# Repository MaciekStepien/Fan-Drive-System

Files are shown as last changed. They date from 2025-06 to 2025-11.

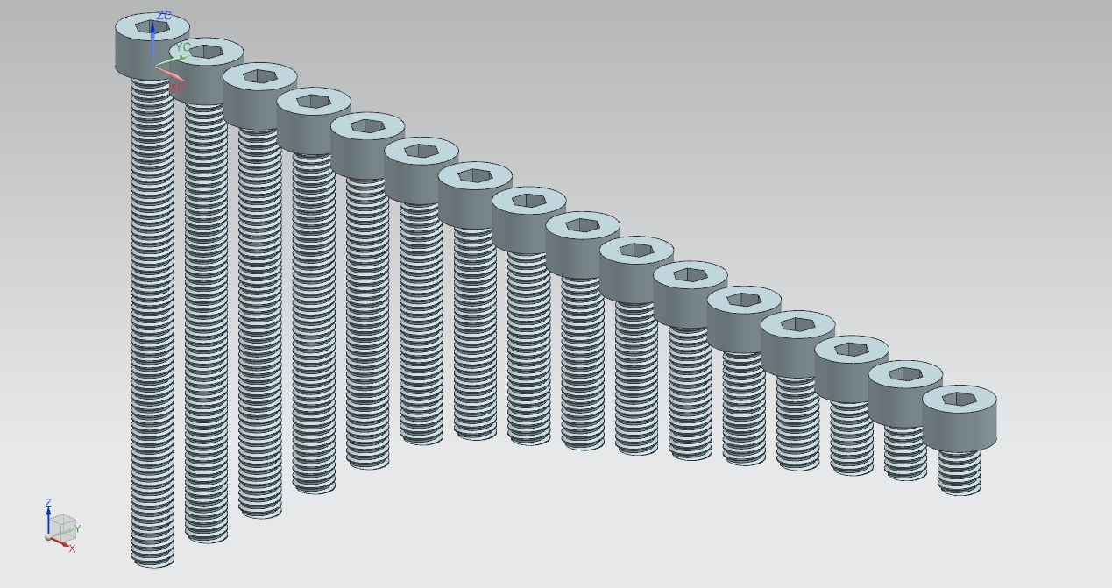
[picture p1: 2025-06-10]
Model/M4 Allen screws/Renderings/M4.jpg

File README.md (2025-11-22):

## About

This repository includes the complete design of a Fan Drive System, developed using Siemens NX CAD software. The project showcases:

- A parametric 3D model of the Fan Drive System enabling flexible design adjustments.
- A technical report providing detailed engineering calculations that support design decisions.
- Precise technical drawings extracted from the CAD model for manufacturing and review.

This work demonstrates practical expertise in computer-aided design, mechanical engineering analysis, and power transmission system design relevant to rotating machinery.

---

## Repository Structure

- `Model/` — Siemens NX model files containing all parametric design data
- `Drawings/` — Technical drawings in PDF format
- `Report_EN.pdf` — Engineering report in PDF format with calculations in English
- `Rerport_PL.pdf` — Engineering report in PDF format with calculations in Polish
- `README.md` — This project overview document

---

## How to Use

- Open the 3D model files in Siemens NX or compatible CAD software to explore, modify, or simulate the Fan Drive System.
- Refer to the engineering report for comprehensive details about design parameters, calculation methodologies, and technical specifications.
- Use the included technical drawings for manufacturing or detailed review purposes.
  
> **Note:** The report was originally written in Polish. The English version has been auto-translated using DeepL for convenience.  
> As a result, the translation may contain inaccuracies. Please refer to the original Polish version for the most reliable information.

---

## Highlights

- Parameter-driven CAD model for easy customization.
- In-depth mechanical analysis to ensure design reliability and performance.
- Detailed drawings suitable for prototyping or production.

---

## Contact

For any questions, feedback, or collaboration inquiries, please get in touch with Maciej Stępień.

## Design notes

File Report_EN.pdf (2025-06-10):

## Faculty of Power and Aeronautical Engineering Institute of Aeronautical Technology and Applied Mechanics Department of Fundamentals of Construction

## Fundamentals of Mechanical Engineering VI

# Fan Drive Transmission System

Performed by: Maciej Stępień | Verified by: Marcin Obszański

Subscribe to DeepL Pro to translate larger documents. Visit www.DeepL.com/pro (https://www.deepl.com/pro?cta=edit-document&pdf=1) for more information.

## Table of Contents

1 | Introduction | 4
1.1 | Outline drawing | 4
1.2 | Design assumptions | 5
1.2.1 | Gabarites | 6
1.3 | Materials used in the device | 7
1.4 | Safety factor | 7
2 | Motor selection | 7
3 | Belt transmission | 8
4 | Shaft loads | 9
4.1 | Shaft diameter arrangement | 9
4.2 | Shaft statics | 10
4.3 | Distribution of effort components | 11
5 | Determination of shaft diameters | 13
5.1 | Ad hoc strength | 13
5.2 | Static stiffness of the shaft | 13
5.3 | Critical rotation of the shaft | 14
5.4 | Fatigue strength analysis of the shaft | 14
6 | Bearing selection | 16
7 | Inlets | 17
8 | Frame statics | 17
9 | Description of the belt tensioning system | 19
10 Sources | 19

## 1 Introduction

The purpose of this work is to design a transmission system for a fan, driven by an electric motor, from which torque is transferred to the shaft by means of a belt transmission, equipped with a belt tensioning system. All components of the device are mounted on a welded frame. The shaft is bearing between the fan and the passive pulley.
1.1 Drawing illustrative

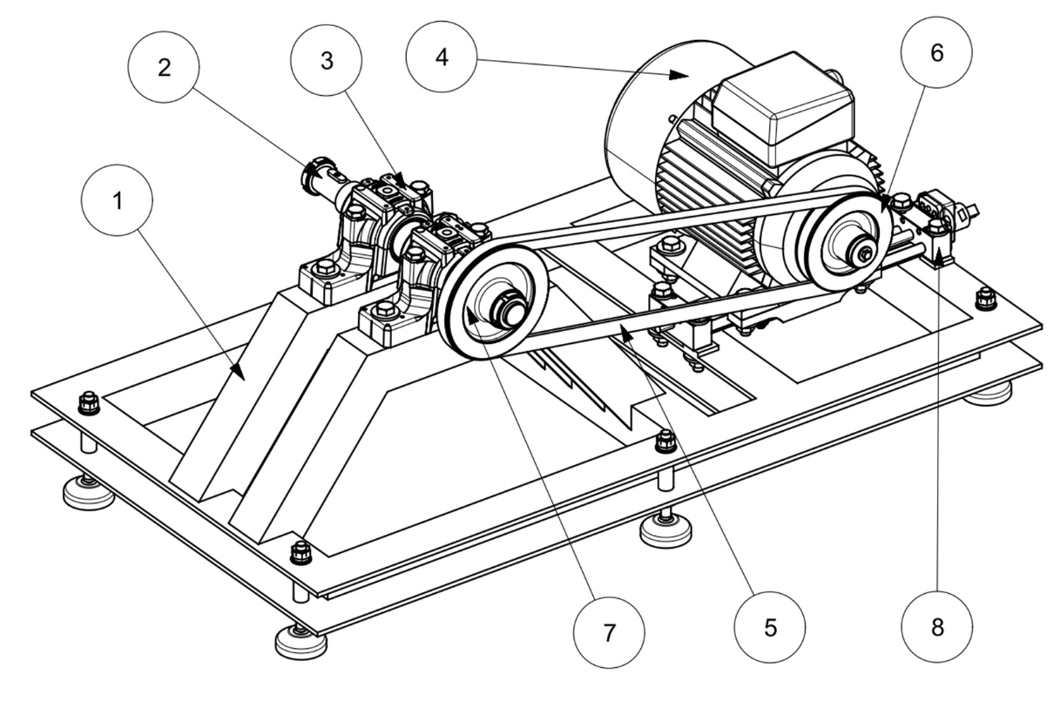
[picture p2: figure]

Main components:

### 1. Frame 2. Drive shaft 3. Bearing housing with bearing 4. Electric motor 5. V-belt 6. Small pulley 7. Large pulley 8. Linear table

1.2 Assumptions design

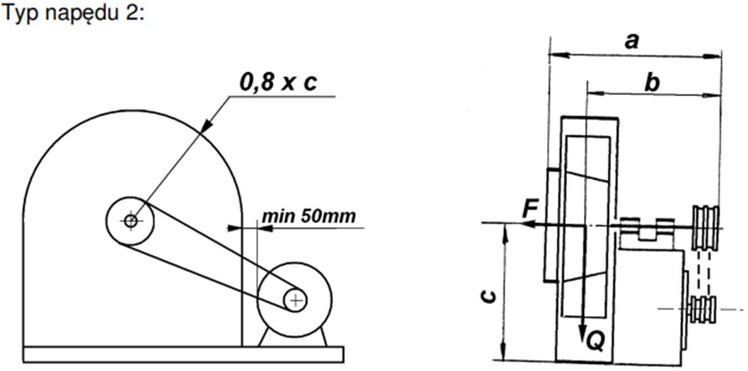
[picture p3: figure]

- two shaft supports are located between the pulley and the rotor

### - power P= 1.2kW

- rotational speed n= 1200 rpm
- axial force F= 310N
- rotor weight Q= 126N
- hourly life L10h= 130000h
- width of the device along the shaft axis a= 505mm
- distance from the center of gravity of the rotor to the opposite end of the shaft b=440mm (later changed to b= 383)
- height of the shaft axis from the ground c= 320mm
- spacing between motor and rotor housing - min 50mm

1.2.1 Gabaryty

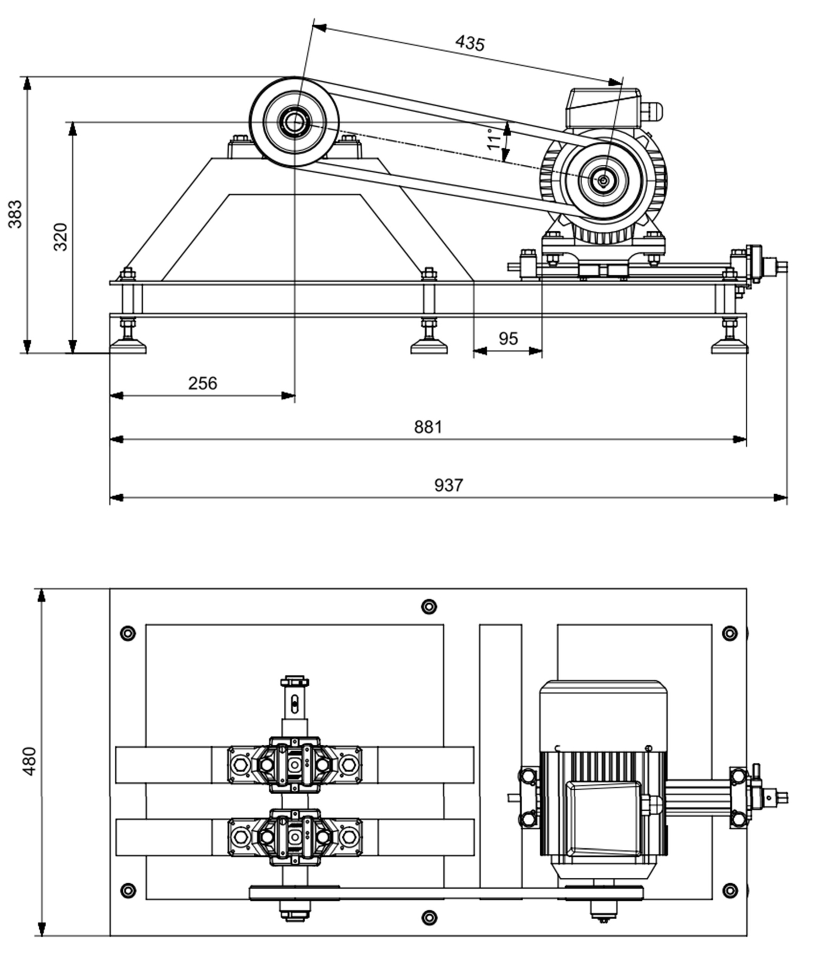
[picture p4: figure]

1.3 Materials used in device
- shaft, disc protection disc on motor shaft: C35 (Re= 270MPa, Rm= 520MPa, Zsj= 244MPa, Zgj= 364MPa, Zso= 150MPa, Zgo= 250MPa)
- Frame, engine mounting table: S235JR (Re= 235MPa, Rm= 410MPa)
- pulleys: St3SX (Rm= 360MPa)
- keys: C45 (Re= 360MPa, Rm= 610MPa, Zsj= 340MPa, Zgj= 480MPa, Zso= 170MPa, Zgo= 280MPa)
- Bushings for pulley, rotor: AISI 303 (Re= 190MPa, Rm= 500MPa)
- shims under the guide: SBR rubber

The selection of materials was based on an analysis of similar components available on the market. All other parts are standardized and made by third-party manufacturers.

1.4 Factor safety
The designed device is to operate most of the day, under moderate loads. The adopted safety factor is x=4.

## 2 Selection of

motor | Pwy
| 5upn

1,2 kW
=
0,945

= 1,269 kW

Assuming 5upn= 5p.belt ∙ 5bearings= 0.95∙ 0.995 = 0.94525 [1]. SH 90 L-4 motor

with parameters was selected:
- Rated powerPse= 1.5 kW
- Speed n= 1410 rpm

The motor meets the design requirements by a margin. In addition, reduce the speed and power of the motor.

## 3 Transmission belt transmission

The designation and selection of belt transmission components were made based on [2]. A SPA V-belt was decided upon. Calculations were made on pulley diametersdp= 100 andDp= 118 (normalized values, selected on the basis of [2]).

The value of the actual ratio of such a gearbox is:
Dp

## irz=

d

118
= = 1.18
100

While the necessary gear ratio, resulting from the characteristics of the selected engine and from the project's assumptions, is:

The ratio error is:
irz−i
i

i= 1.175

- 100%= 0.425%

According to [1], this is an acceptable error.

Then calculated / selected (based on [2]):

- WheelbaseA0:

AdoptedA1= 0.435 m

- Lane lengthLp:

A0min= 0.7∙ (D(p)+d(p)) = 0.1526 A0ma=2∙ (D(p)+d(p)) = 0.436

2
(D(p)−dp)
Lp_calculated= 2 ∙A + 1.57∙ (D(p)+d(p) ) + | = 1,212 m
4A
The normalized lane lengthLp= 1,207m , according to [2], was assumed.
- Exact wheelbase :A

Where:

A≈p+√p²−q= 0.432m

p= 0.25L(p)− 0.393(D(p)+dp) = 0,216

2
q= 0.125(D(p)−dp) = 3.83∙ 10
- Operating conditions factor:kt = 1.2, assuming an operating time of more than 16 hours per day for light drive
- Banding factor:kφ= 0.99
φ

## cos

2

Dp−dp =
2A

→ φ= 177.68°
- Lane length ratio: kL= 0.88
- Rated power:N1= 2.54 kW

p

-5

dyn

- Required number of transmission belts:
z =

N∙kt = 0,813

N1∙kφ∙kL
Rounding up, a single belt was used in the gearbox.

The forces acting on the belt, were also calculated according to [2]. In the design, the case that is most "dangerous" for the system should be checked. Therefore, it was decided to take into account the dynamic force.

- Dynamic axle load from forces in the passive tendons:
1020∙ (1.02 −kφ) ∙N∙kt
T(b) ≈ | kφ

= 7,536 N
- v

Where the lane movement speed: v= 7.38 m/s

- Dynamic axle load from forces in active tendons: 1020 ∙N ∙ kt
T(c) ≈
- Accidental dynamic force:

kφ

= 251,2 N
- v

Ns ≈√Tc
2+Tb

2+ 2 ∙Tc∙Tb∙ cosφ= 258.73 N

## 4 Loads shaft

4.1 Arrangement of diameters of the shaft

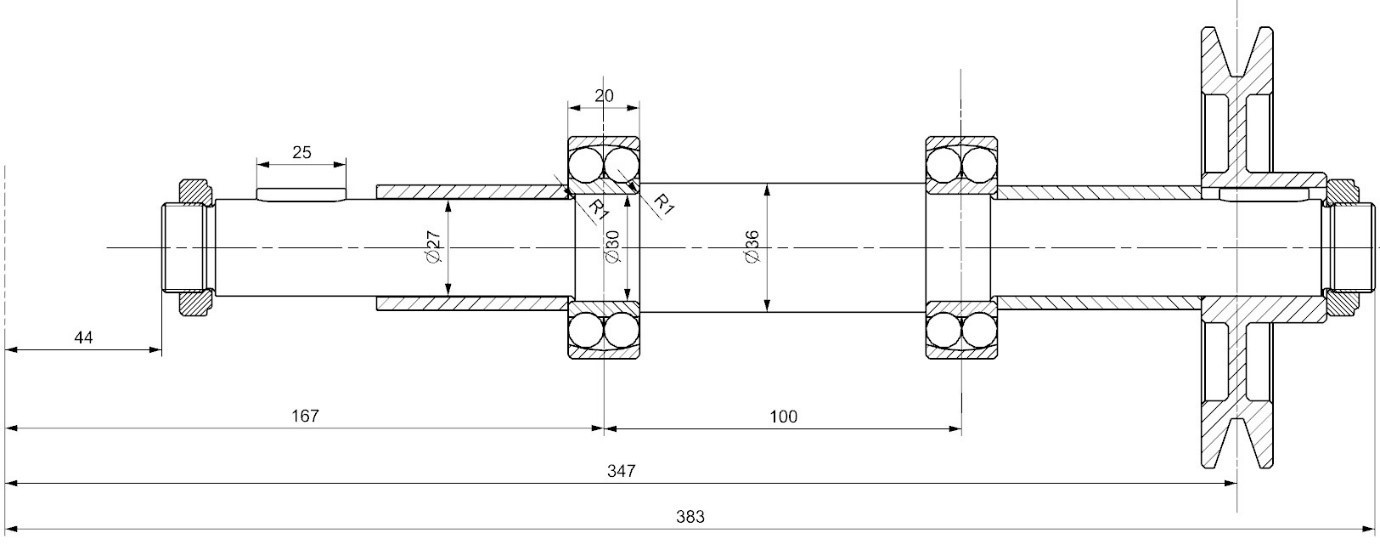
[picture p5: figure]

The above figure shows the arrangement of the various elements on the shaft, the distances between them and the lengths of the various segments of the shaft.

4.2 Statics of the shaft

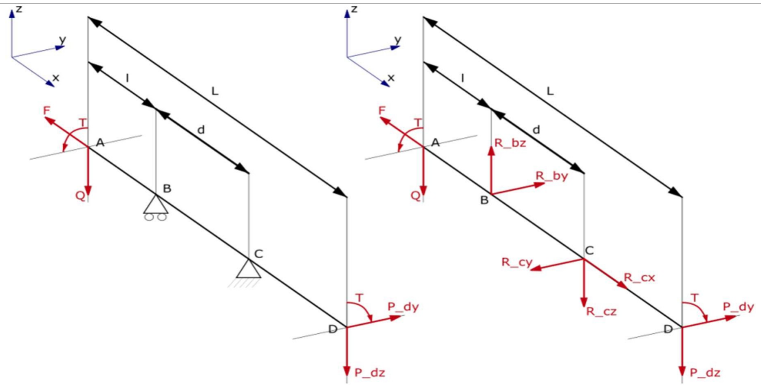
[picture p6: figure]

Data adopted for calculations:

Designation | Value | Unit
L | 0,347 | m
l | 0,167 | m
d | 0,1 | m
F | 310 | N
Q | 126 | N
T | 11,94 | Nm
P_dy | 255,32 | N
P_dz | 41,81 | N

Where the torsional moment from the belt: T=⁽N∙D) (p)

2v
Dynamic force component on y-direction: Pdy=Nsdyn∙ sin α

Dynamic force component on z direction: Pdy =Nsdyn∙ cos α

Where alpha is the angle between the vertical and the dynamic

force from the chord

Freeing the system from ties and calculating the reaction forces in the supports, we get:

Designation | Value | Unit
Rbx | 0 | N
Rby | 204,3 | N
Rbz | 303 | N
Rbw | 365,69 | N
Rcx | 310 | N
Rcy | -459,6 | N
Rcz | 135,2 | N
Rcw | 479 | N

Where
Rbw =√R by

2+R bx

2

Rcw =√R cy

2+R cx

2

The non-sliding base was placed in a more stressed position.

4.3 Distribution of components of effort
All calculations were carried out assuming, the theoretical case in which the shaft starts at the center of gravity of the fan.

## ZX plane

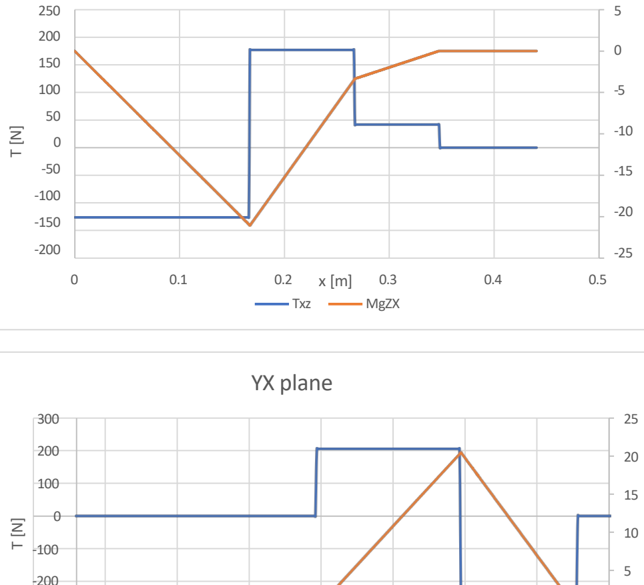
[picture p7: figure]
MgZX; Txz; YX plane
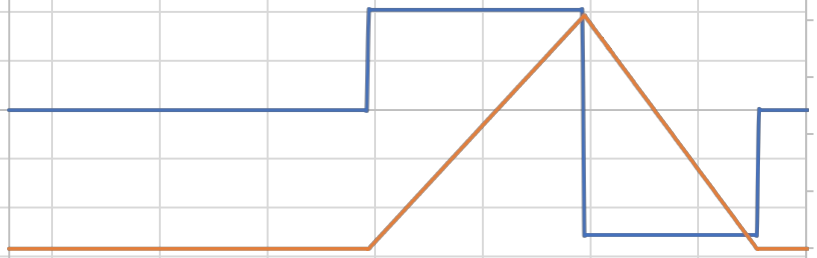
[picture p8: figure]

MgYX

0.17 | 0.22 | 0.27 | 0.32 | 0.37
x [m]
Tyx
0.02 | 0.07 | 0.12
-400 | -5
-0.03
| 0 -300

-200

M [Nm] M [Nm]

After determining the basic load distributions on the shaft, the resultant and equivalent bending moment were calculated:

Mgw =√M yx

2+M zx

2

Mzast=√M(gw) (2)+ (α ∙T )

2

Where α =√

3
4

## Replacement torque 60

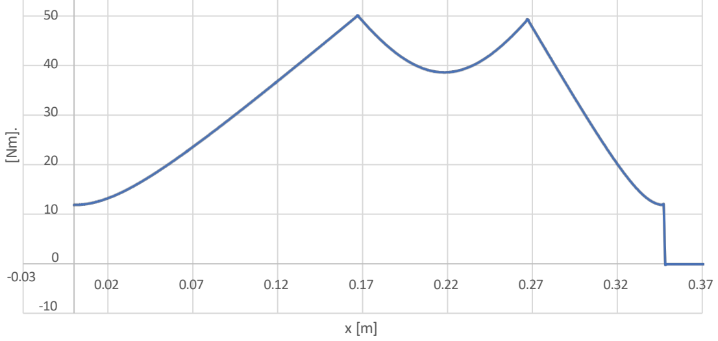
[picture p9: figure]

r>=

## (theor) 0.009

## 5 Determination of shaft diameters

5.1 Strength ad hoc
When determining the theoretical diameter, axial loads were ignored - they have a marginal effect on the obtained results.

Where: x= 4, whileZgo= 250 MPa

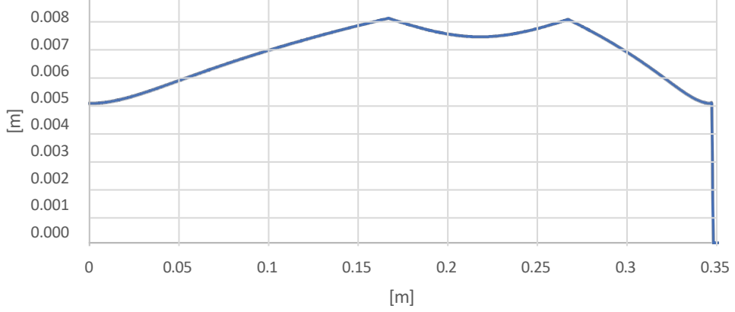
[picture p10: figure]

5.2 Static stiffness of the shaft
A diameter that is the arithmetic average of the two extreme diameters on the shaft was used to calculate the deflection line:
d =

Dmin +D max
2

0.027+ 0.36
=
2

= 0,0315

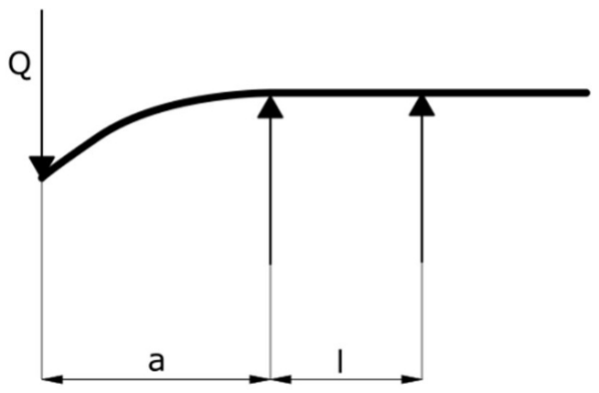
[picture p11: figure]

In addition to this, the load from the gearbox was ignored - only the force is responsible for the deflection . To calculate the deflection line, the formula was used:
Q∙a

2
f = ∙ ( l+ a ) = 3.08∙ 10⁵m 3EJ

Designation | Value | Unit
Q | 126 | N
E | 210 | GPa
J | 4.83∙ 10⁻⁸ | m⁴
l | 0,1 | m
a | 0,167 | m
Where, E is the Young's modulus of C35 steel, and the bending moment of inertia: J= π∙d

4
64
According to [3], the deflection arrow must meet the condition: f= (2÷ 3⁾∙ 10⁴∙l= (2÷ 3⁾∙
10⁵ m

The requirement was not met. After analysis of the critical rotation and consultation with the instructor, the deviation was found to be acceptable.

5.3 Critical rotation of the shaft
The critical speed was obtained from the relationship: :
g | 9,81 | rad

## ωkr=√

f

=√

3.08∙ 10⁵=564 | = 5388 rpm
| | s

The critical speed is more than 4 times the required speed - the shaft meets the requirements.

5.4 Fatigue strength analysis of the shaft
For the fatigue strength analysis of the shaft, 2 cross-sections were selected that may prove to be "weak links". These are the location of the diameter change from the largest diameter to the diameter of the journal on which the bearings are mounted, and the location of the keyhole.

The diagram below shows the moments that were taken into account in the calculations: M [Nm].

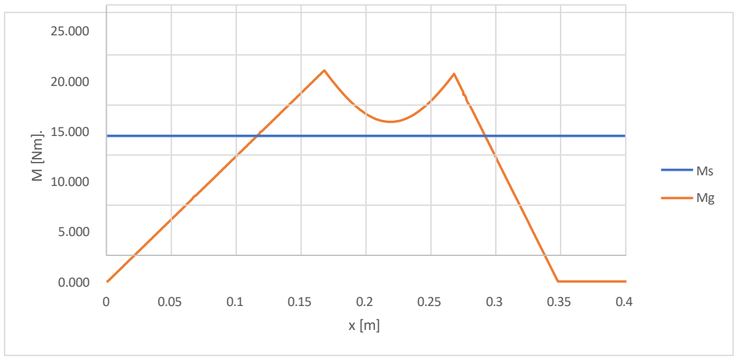
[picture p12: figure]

These moments for the counted points are respectively:

x [mm] | M [Nm] | Ms [Nm]
90 | 11.34 | 11.93
177 | 19.38 | 11.93

Coefficients for calculations:

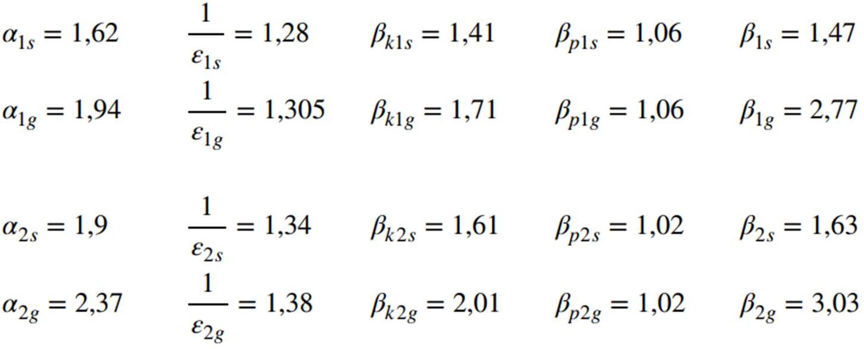
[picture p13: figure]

Tensile indices and stresses in successive sections:
W1s | 254 | W1g | 127 | W2s | 176.7 | W1g | 88.3
r1sa | 23.44 | σ1 | 89 | r2sa | 33.7 | σ2 | 219
r1sm | 23.44 | - | - | r2sm | 33.7 | - | -

Coefficient psi = 0.05 for steels with medium carbon content. Then fatigue safety stocks:
σ1s | 151.47 | σ2s | 195.4
σ1g | 23.39 | σ2g | 17.65

Accidental safety stocks:
σ1 | 24.76
σ2 | 17.34
All | received | results are many times | greater | than adopted safety factor
x=4.

## 6 Selection of bearings

Using the SKF website, self-aligning ball bearings 2206 ETN9 and housings SNL 206-
305. bearing parameters can be found in the table below:
Designation | Value | Unit
dw | 30 | mm
Dz | 62 | mm
B | 20 | mm
C | 23,8 | kN
C0 | 6,7 | kN
Pu | 0,345 | kN
e | 0,33 | -
X | 0,65 | -
Y2 | 1,9 | -

In this subsection, the bearing life is checked. Only the more exposed bearing, locked in the x-axis and loaded longitudinally, is checked. Calculations were carried out according to the scheme in the SKF bearing catalog [4].

Forces acting on the bearing:

- Rcw= 479N - lateral force
- Rcx= 310N - axial force

Thus:

## Rcx Rcw

= 0.647> 0.33

Fzast=X∙Rcw+Y2∙Rcx= 900.4 N

Hourly bearing operation time to destroy 10% of the sample:

L10h =

10⁶ C
(

p
)= 256515 ℎ
60 ∙n Fzast
Where p= 3 for ball bearings.

The bearing will last the required 130,000 hours of operation.

1

## 7 Grooves

Based on [1], a prismatic keyway was selected with dimensions: 8x7x25 mm. Calculations were carried out for the data:

Designation | Value | Unit
dshaft | 27 | mm
T | 11,94 | Nm
ℎ | 7 | mm
t1 | 4 | mm
L | 25 | mm

The parameters of the grooves are chosen so that the decisive stresses are surface pressures: 2T∙ 10³
pdop=
(ℎ −t ) L∙ d sha
ft

= 14,74 MPa

Thus, the keyway meets the strength requirements [1].

## 8 Statics frame

The frame is made of S235JR structural steel. The component consists of channels welded together. The legs of the device, made on the basis of Kipp's K0742 feet, are arranged by means of welded, unthreaded bushings. The movement of the feet is blocked by a set of nuts and washers, and their design allows easy reduction of unevenness in the ground. Bolted connections with washers were also used to attach the belt tension system and bearing housings.

The stiffness of the structure was examined using the FEA module built into the NX system. The elements directly receiving the loads, i.e. the bearing housings and the motor together with the shaft, were replaced by simple solids. A mesh of dimension was superimposed on such a frame. The calculation results are shown below. The image itself is the deformation scaled by the characteristic dimension.

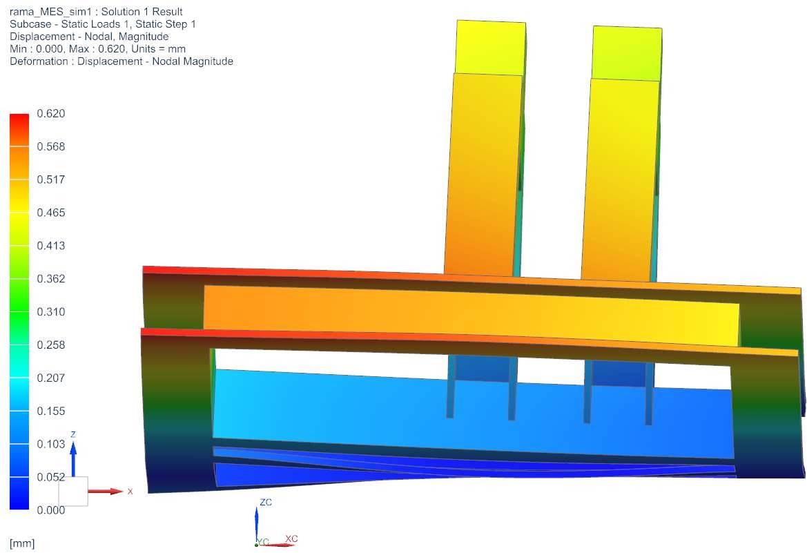
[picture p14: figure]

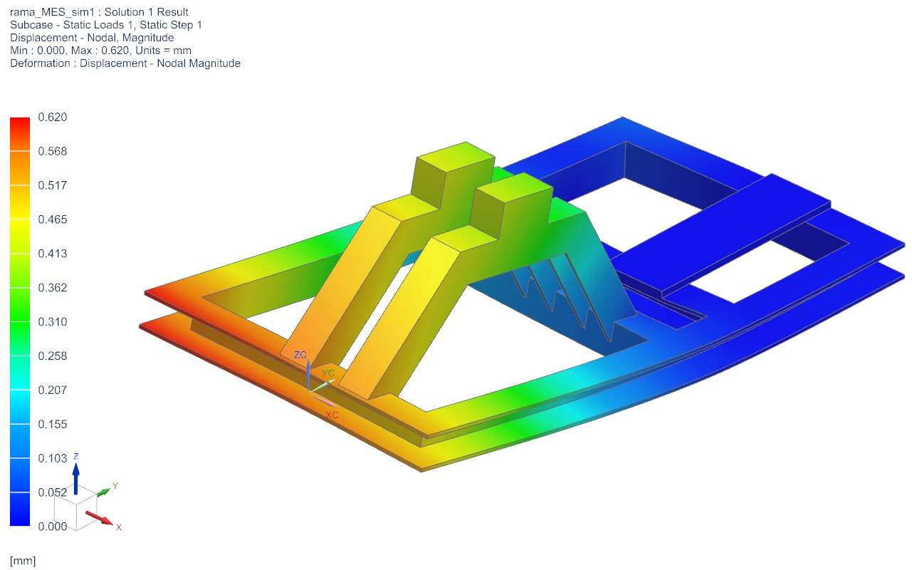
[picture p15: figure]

The maximum deformation is about 0.62 mm - a small and acceptable value in view of the dimensions of the whole system and the presence of the belt tension system, which can compensate for any changes.

## 9 Description of the tensioning system belt

The device uses a belt tensioning system in the form of a sliding motor on a table - SLW- 1040 from igus.

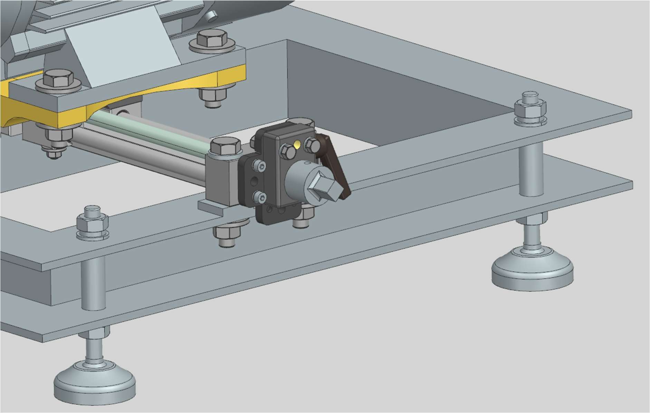
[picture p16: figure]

The maximum axial load capacity of the system is 700N, radial 2800N. The guides provide high rigidity and prevent twisting of the component. A screw in the axis of symmetry of the system is responsible for adjusting the position of the motor. With the help of a grub screw, an adapter for a 10 key is attached to it. The rotation itself is blocked by the SHT-HK-12 manual clamp, connected through an adapter. Both parts were made by the same company.

## 10 Sources

[1] Kurmaz L. W., Kurmaz O. L. Fundamentals of Node and Machine Parts Design. 2011
[2] Starego W., Constructor's Guide (for the design of belt gears) Sanok Rubber. 2017
[3] Mazanek E., Examples of calculations from the fundamentals of amshin design vol. 2
[4] SKF, Catalog of rolling bearings. 2014
[5] Catalog data from websites:
[5.1] https://www.skf.com/pl/productinfo/productid-2209%20ETN9 (as of as of 15/04/2023)

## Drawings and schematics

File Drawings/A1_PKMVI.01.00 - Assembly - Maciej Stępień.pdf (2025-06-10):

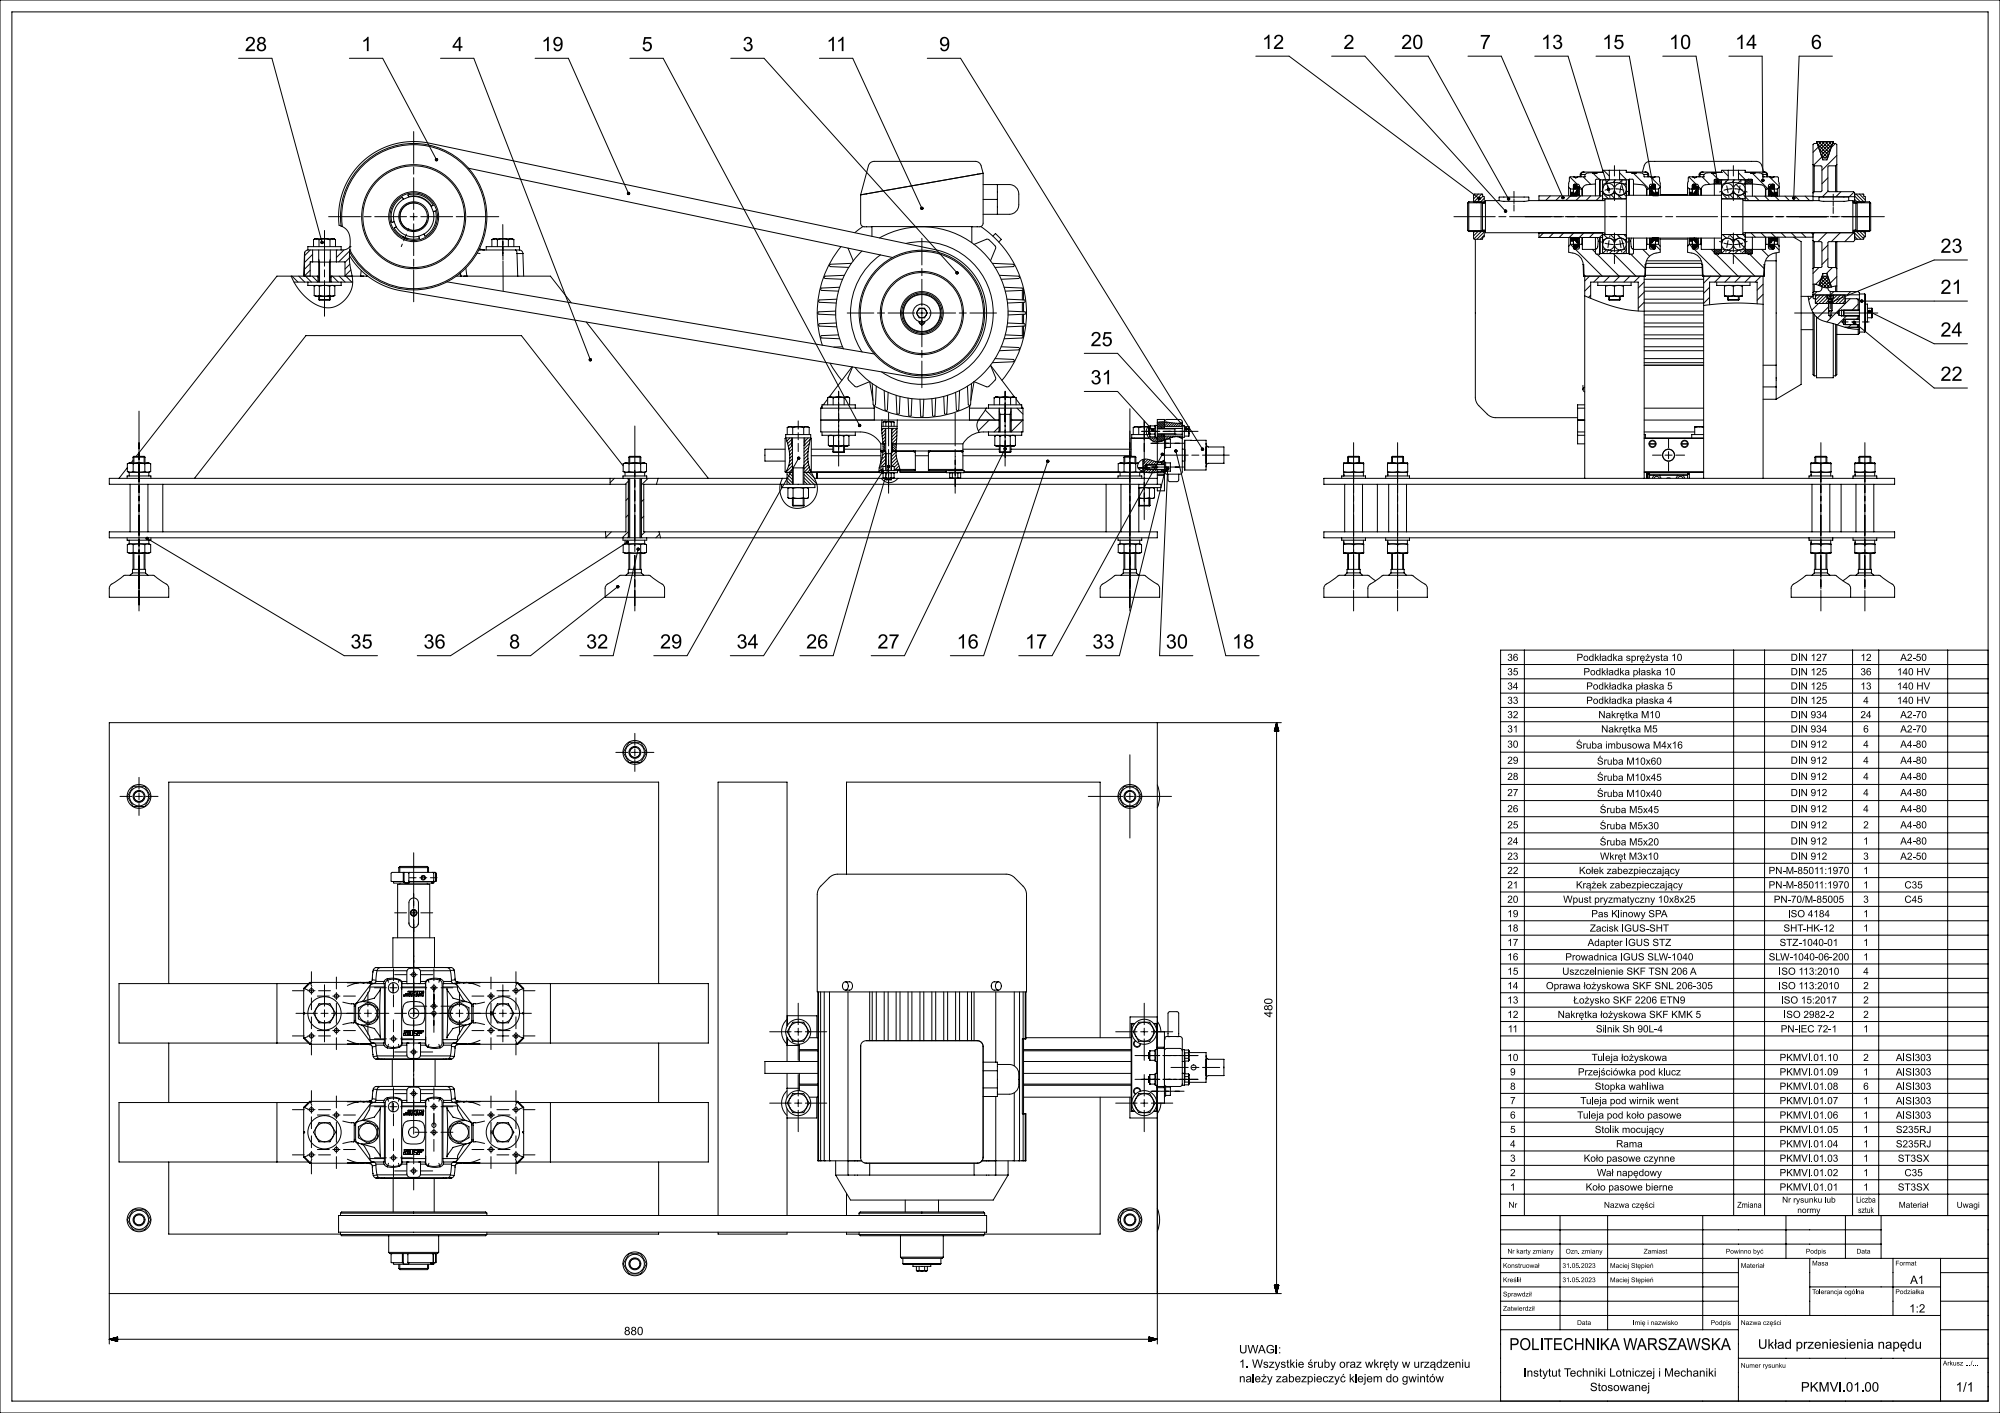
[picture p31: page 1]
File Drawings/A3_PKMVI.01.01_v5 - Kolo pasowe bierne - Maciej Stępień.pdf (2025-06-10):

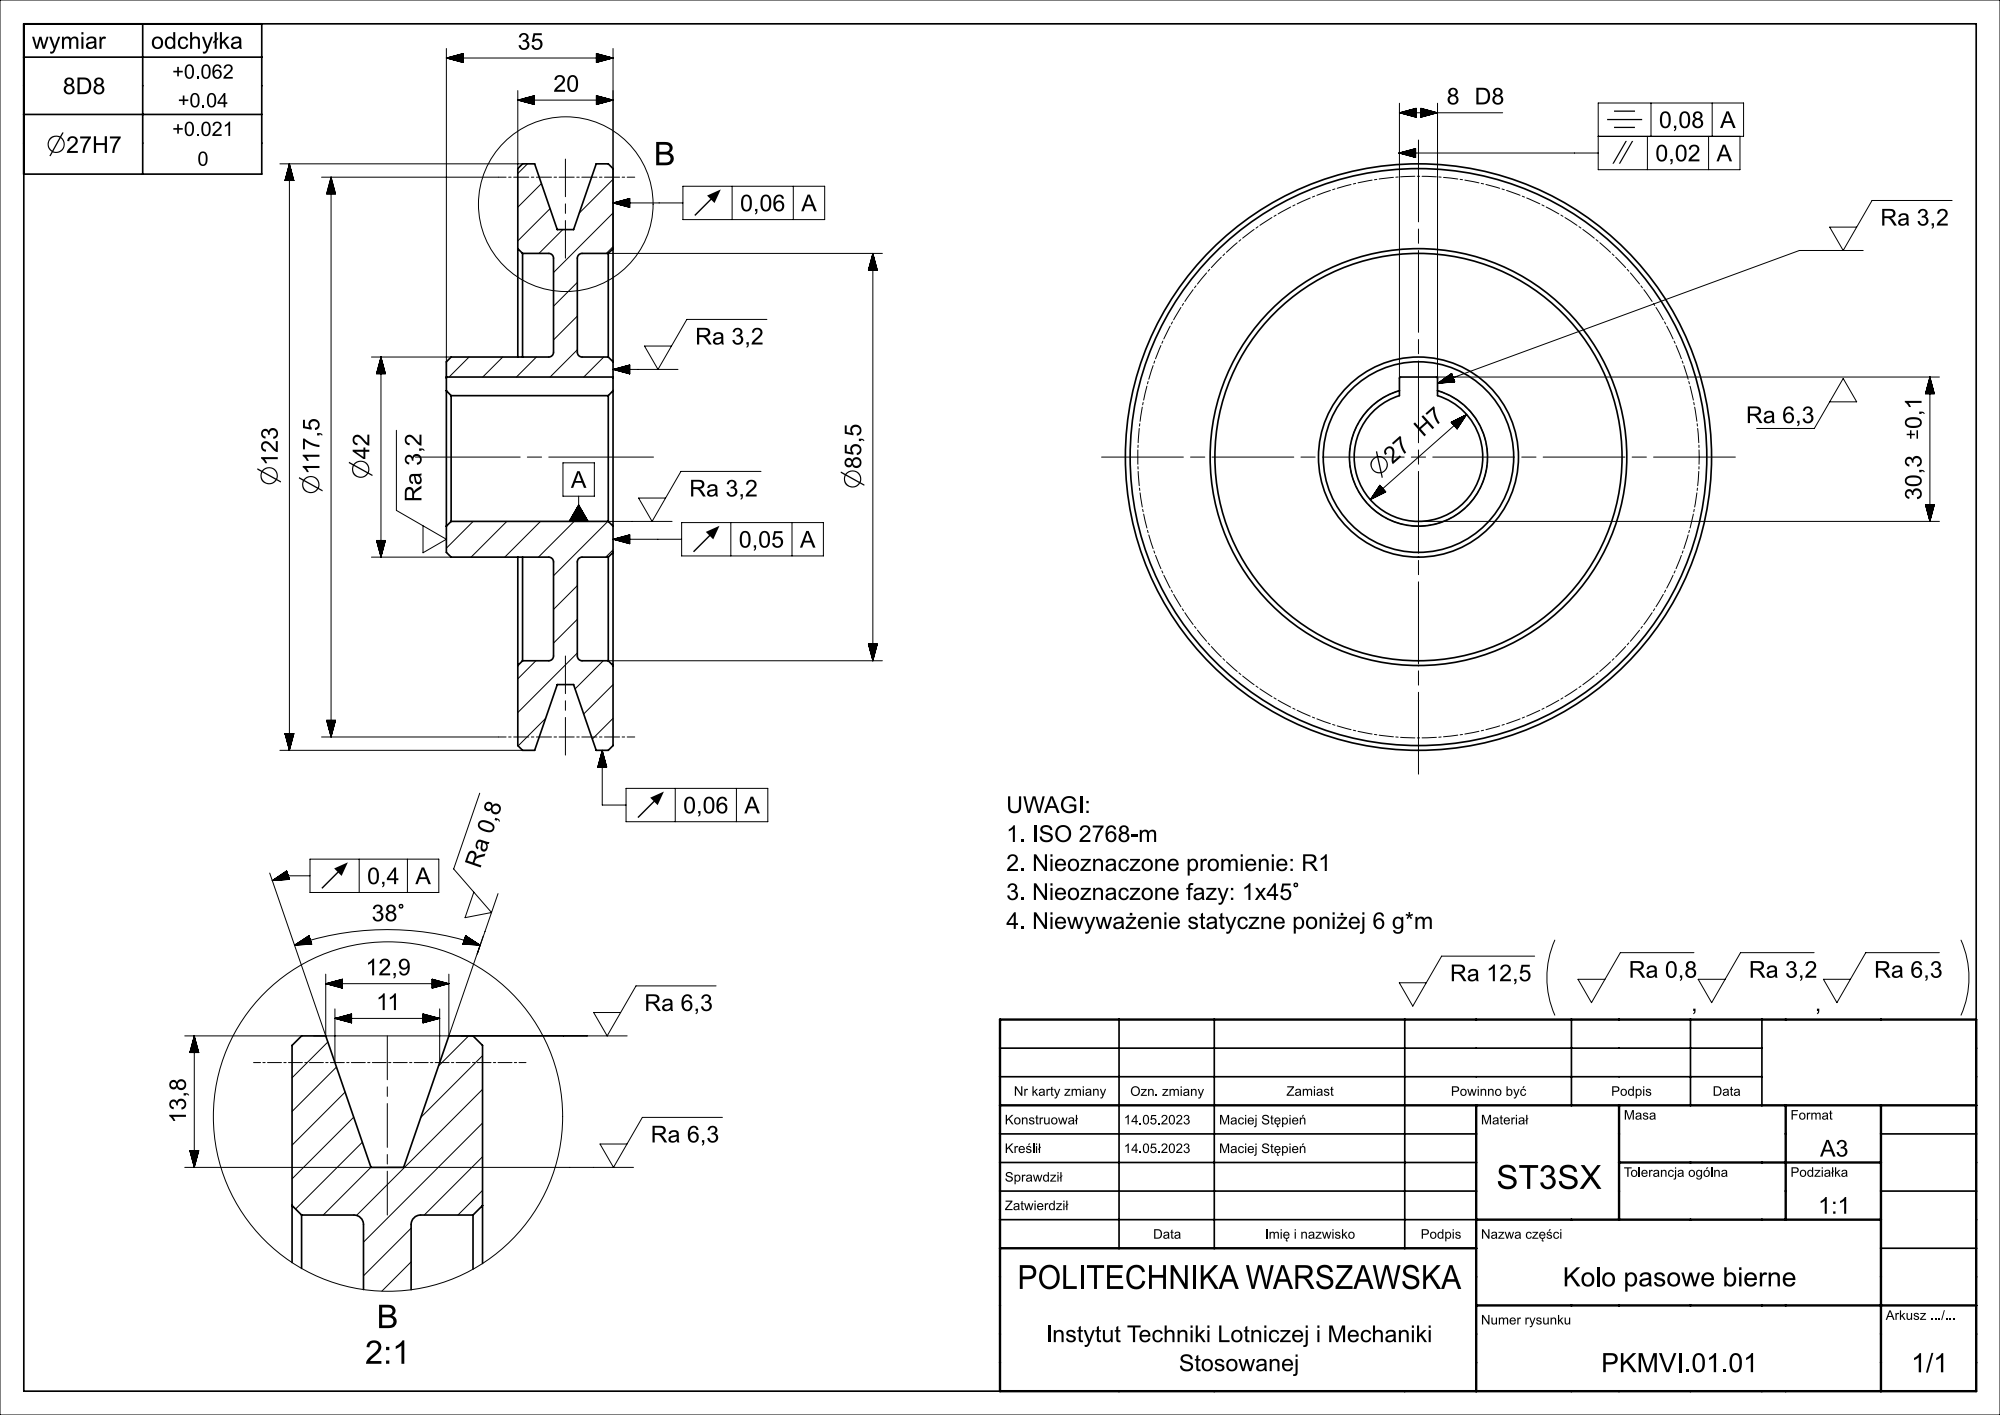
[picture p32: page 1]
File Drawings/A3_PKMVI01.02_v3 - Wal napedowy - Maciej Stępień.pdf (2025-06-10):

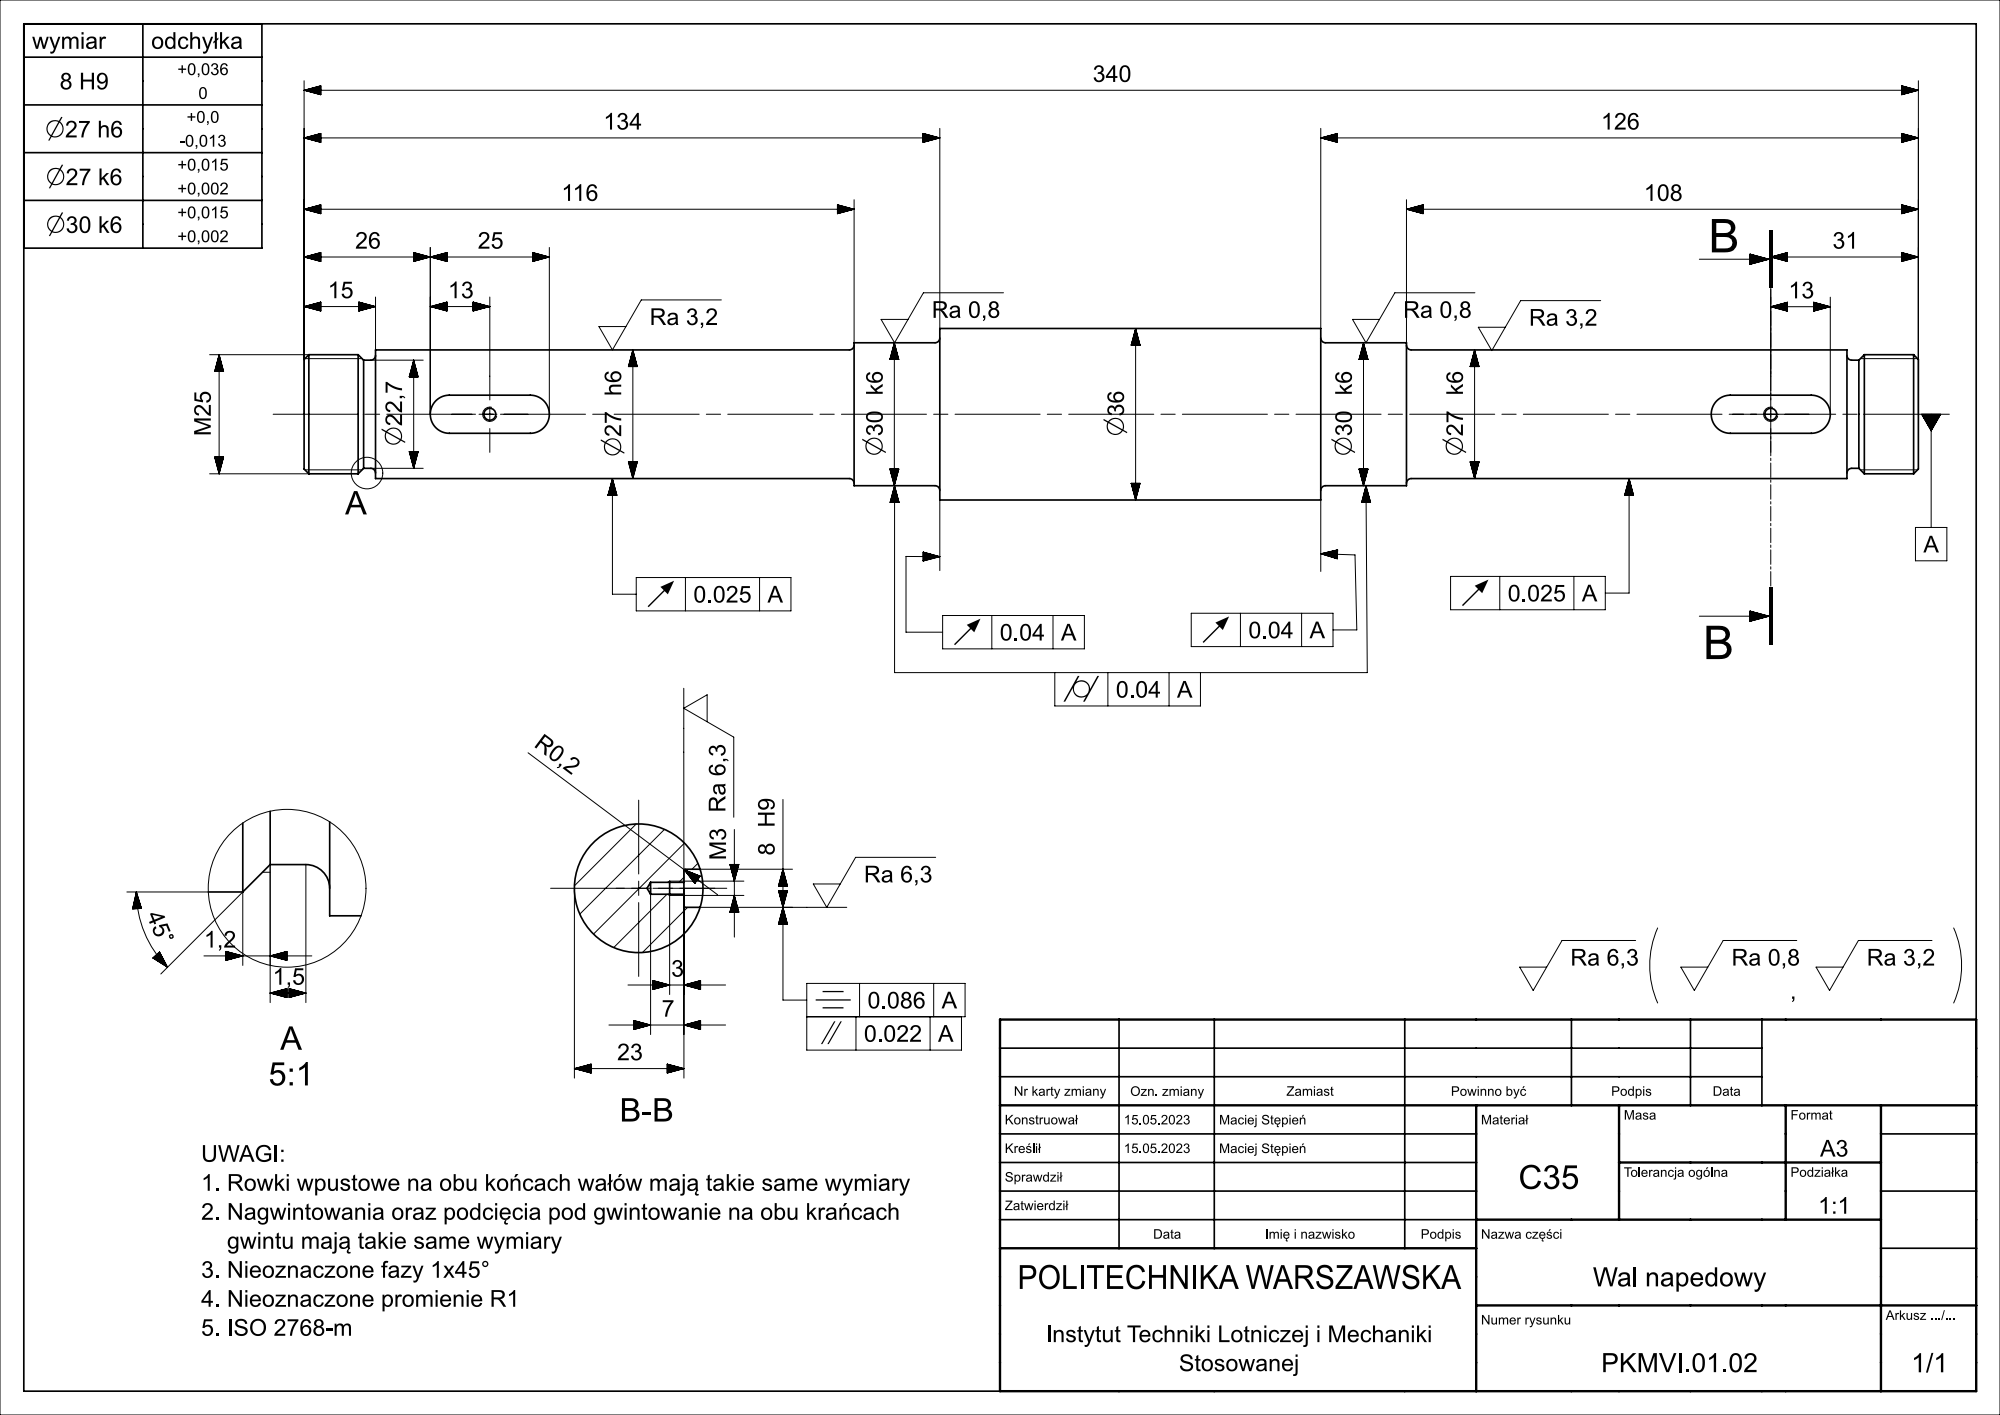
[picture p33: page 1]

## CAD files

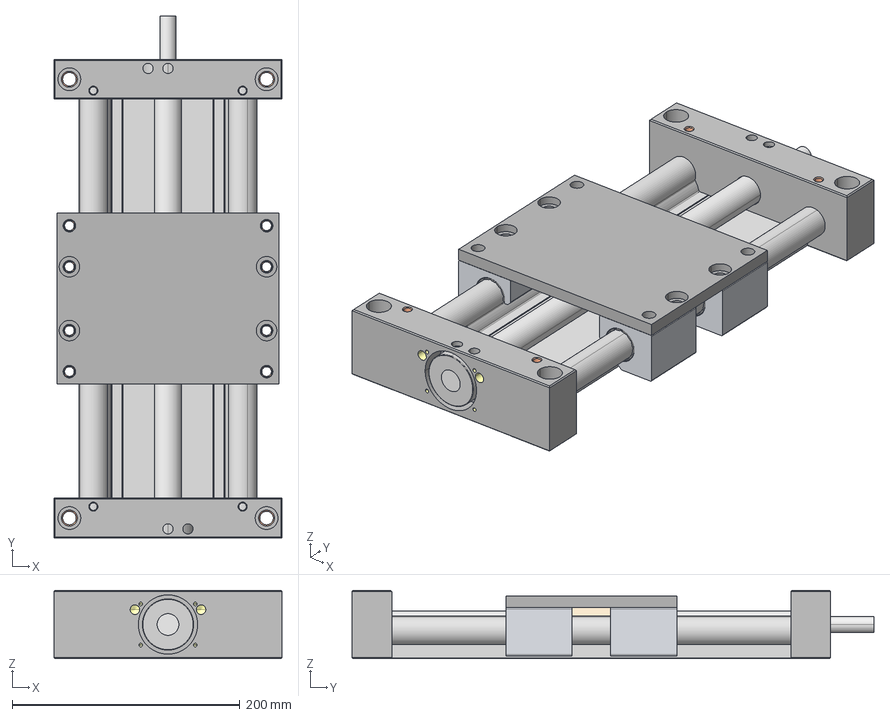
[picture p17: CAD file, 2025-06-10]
Model/Belt tensioner/SLW_25120_15_200_1.stp
200.0 x 458.0 x 60.0 mm

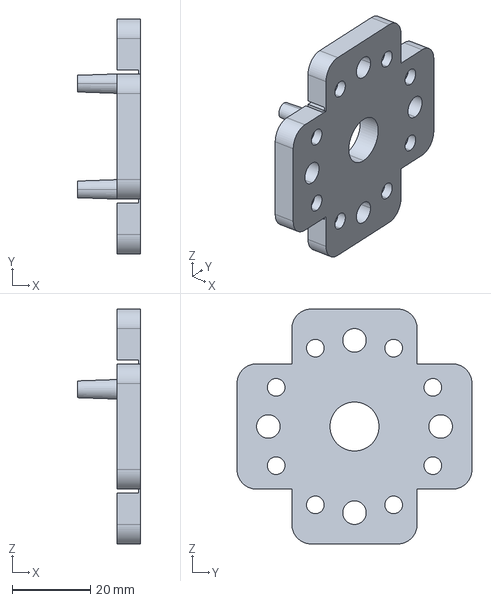
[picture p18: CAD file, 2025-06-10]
Model/Belt tensioner_krotki/sanki/STZ_104001_1.stp
16.0 x 60.0 x 60.0 mm

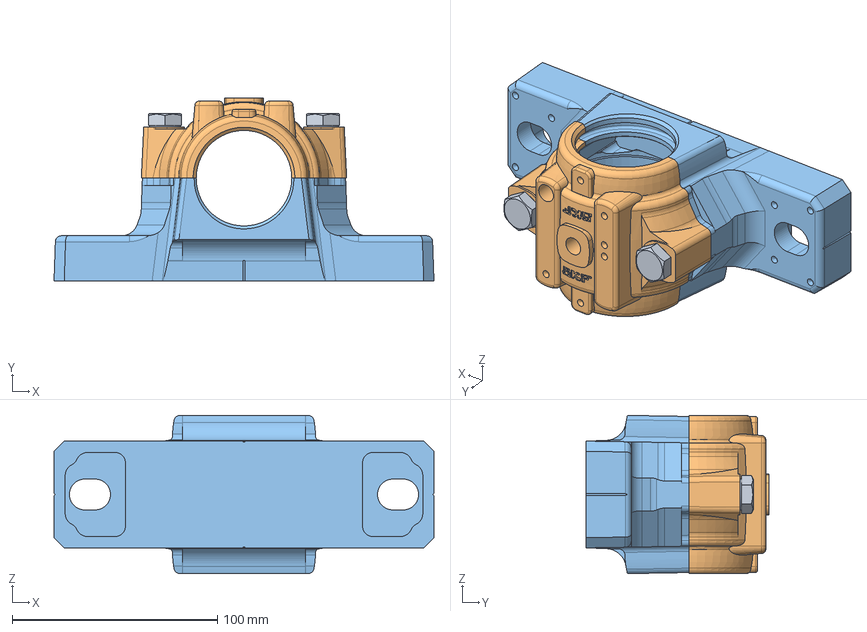
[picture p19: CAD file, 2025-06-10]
Model/Oprawa lozyska/SKF_SNL 206-305.stp
185.0 x 89.0 x 77.1 mm
M10x40-10x40_001 x 2
SNL 206-305_c
SNL 206-305_b

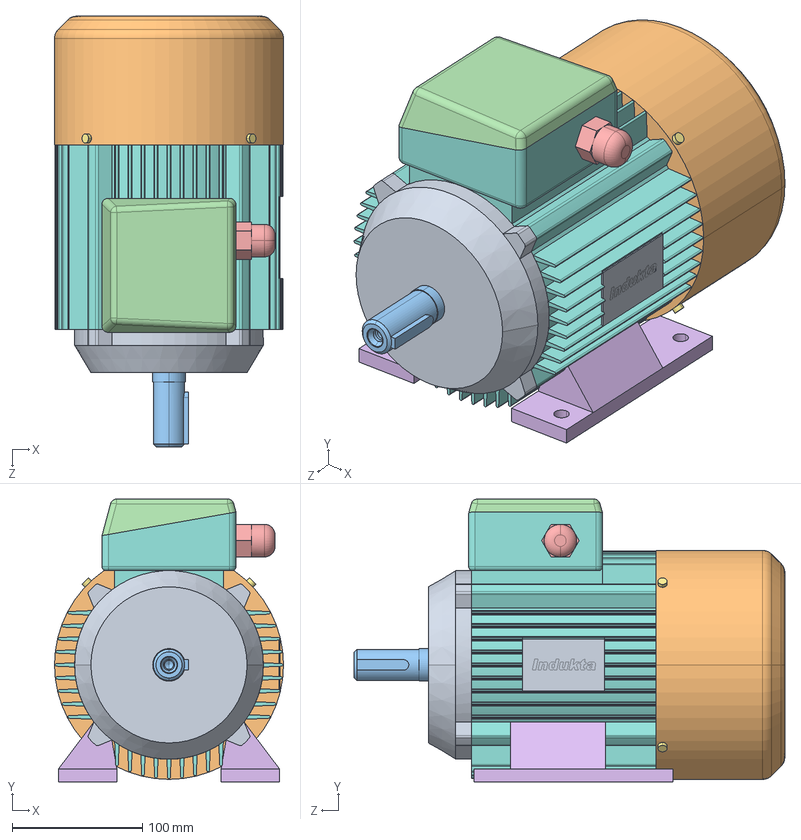
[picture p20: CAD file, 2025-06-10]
Model/Silnik/Sh 90L-B3.STEP
176.0 x 217.5 x 331.0 mm

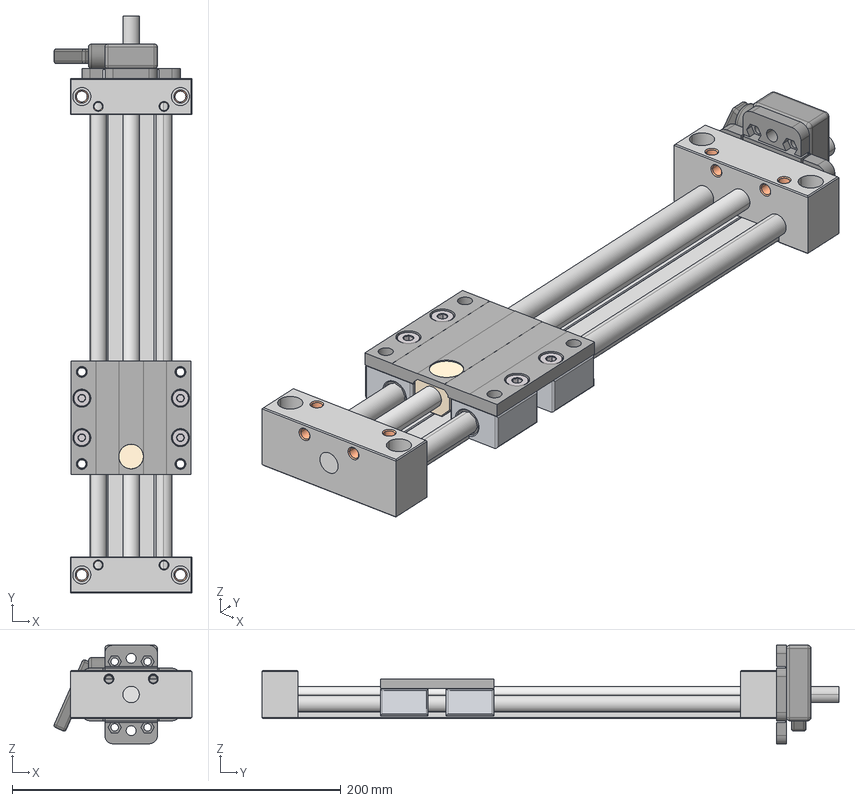
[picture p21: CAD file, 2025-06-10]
Model/Belt tensioner_krotki/sanki/SLW_1040_06_200_HK_4.stp
83.9 x 351.0 x 60.0 mm

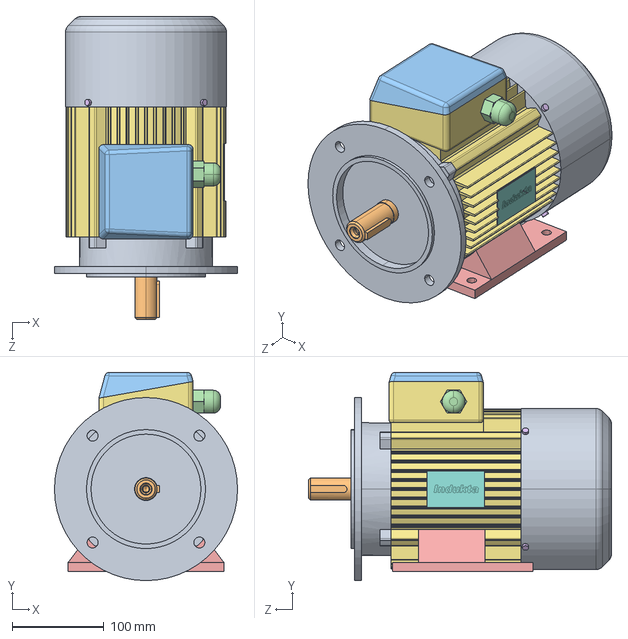
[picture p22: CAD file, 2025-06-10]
Model/Silnik/SLh 90L-B35.STEP
200.0 x 227.5 x 331.0 mm

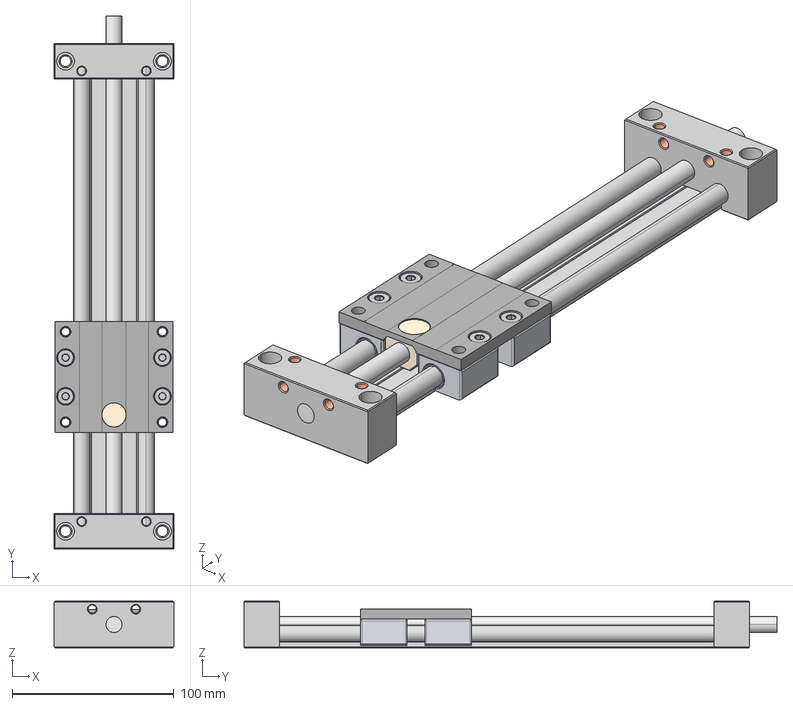
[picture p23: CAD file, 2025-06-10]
Model/Belt tensioner_krotki/sanki/SLW_1040_06_200_3.stp
74.0 x 330.0 x 29.0 mm

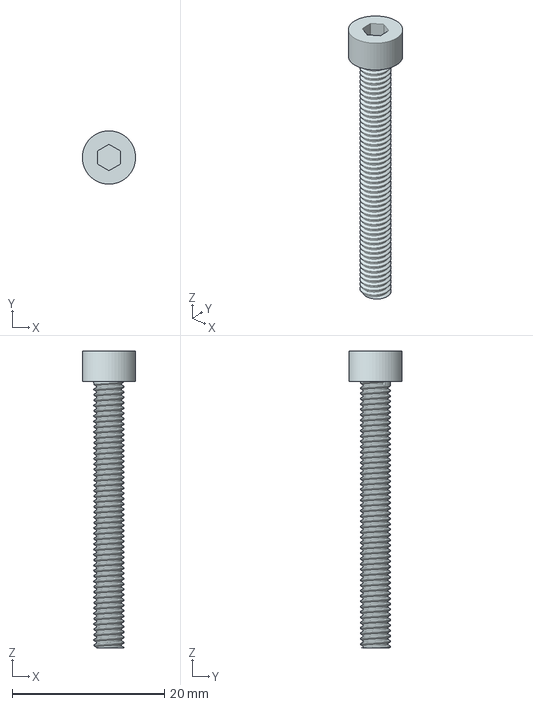
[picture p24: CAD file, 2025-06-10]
Model/M4 Allen screws/stp Files/M4x35.stp
6.99 x 7.00 x 39.0 mm

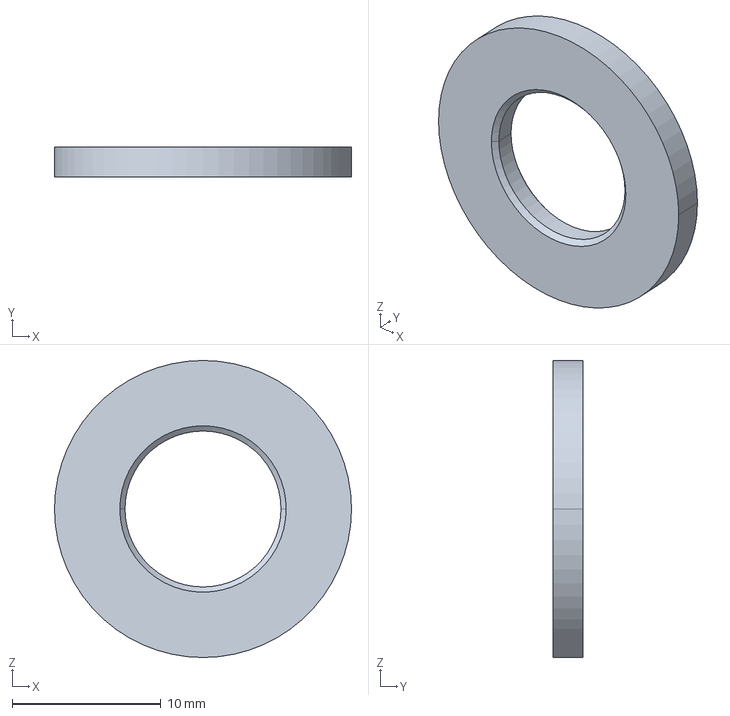
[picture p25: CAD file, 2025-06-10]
Model/Noga/din125-2-a10_5-300_hv.stp
20.0 x 2.00 x 20.0 mm

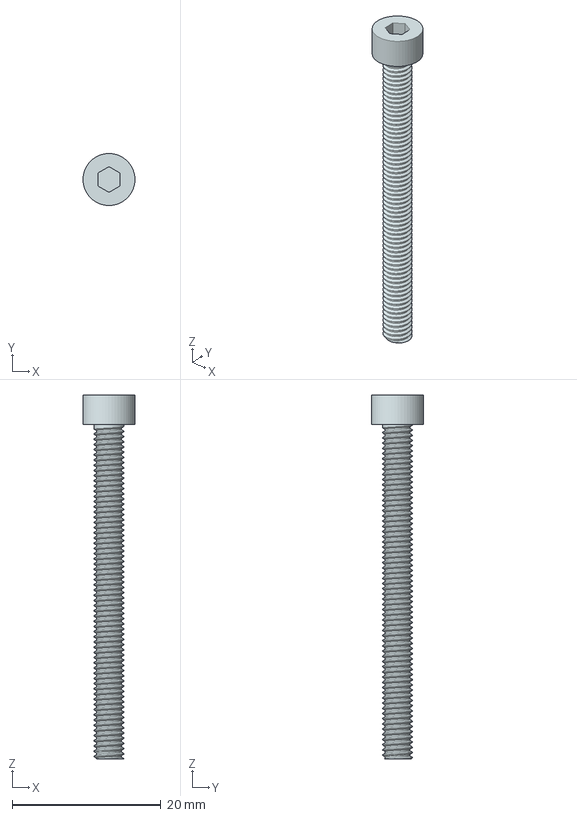
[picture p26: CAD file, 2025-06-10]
Model/M4 Allen screws/stp Files/M4x45.stp
6.99 x 7.00 x 49.0 mm

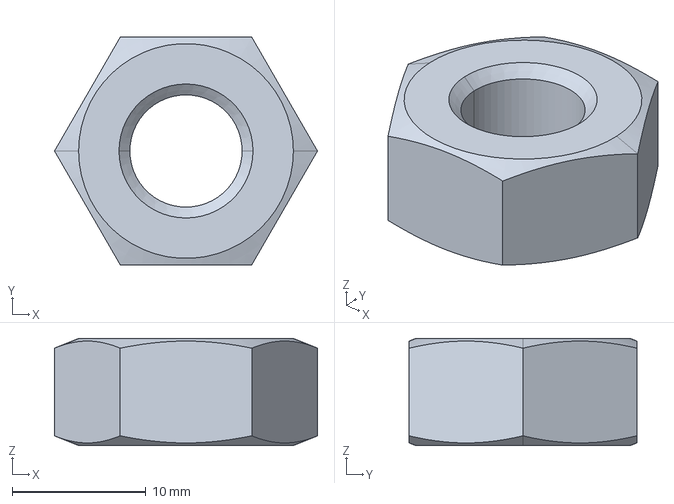
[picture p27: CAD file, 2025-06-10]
Model/Noga/nut_din934_m10-6.stp
19.6 x 17.0 x 8.00 mm

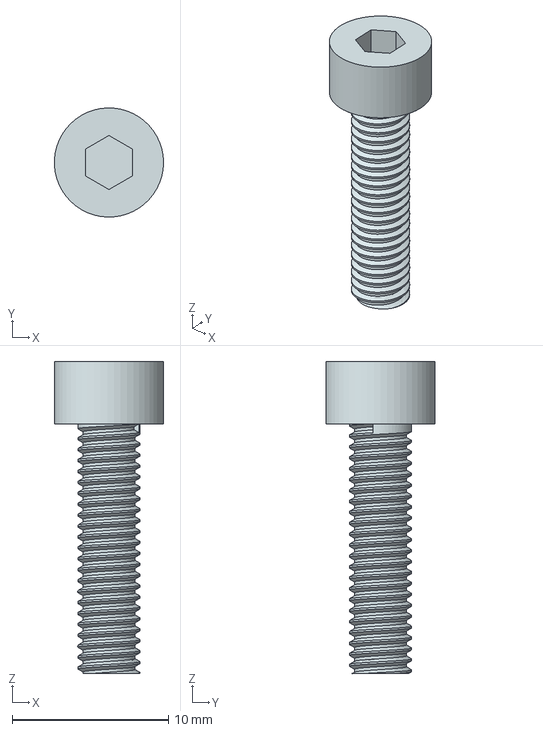
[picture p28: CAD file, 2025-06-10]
Model/M4 Allen screws/stp Files/M4x16.stp
6.99 x 7.00 x 20.0 mm

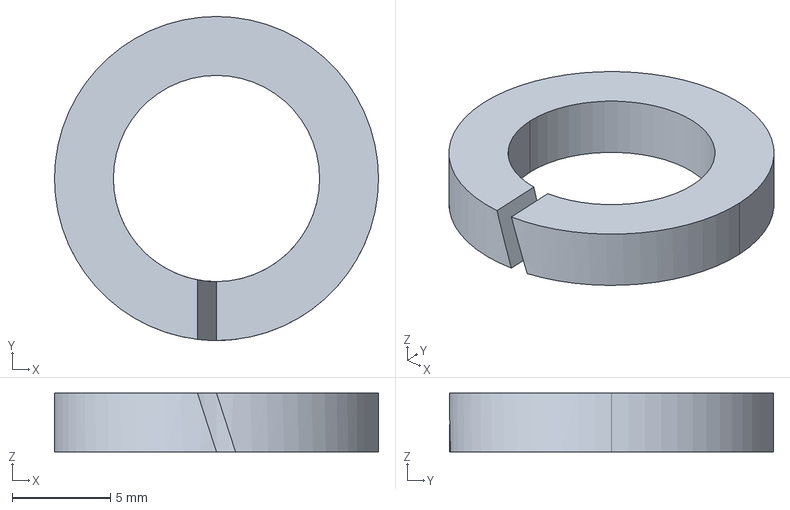
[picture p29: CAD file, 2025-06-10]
Model/Noga/din_127_o10-3.stp
16.5 x 16.5 x 3.00 mm

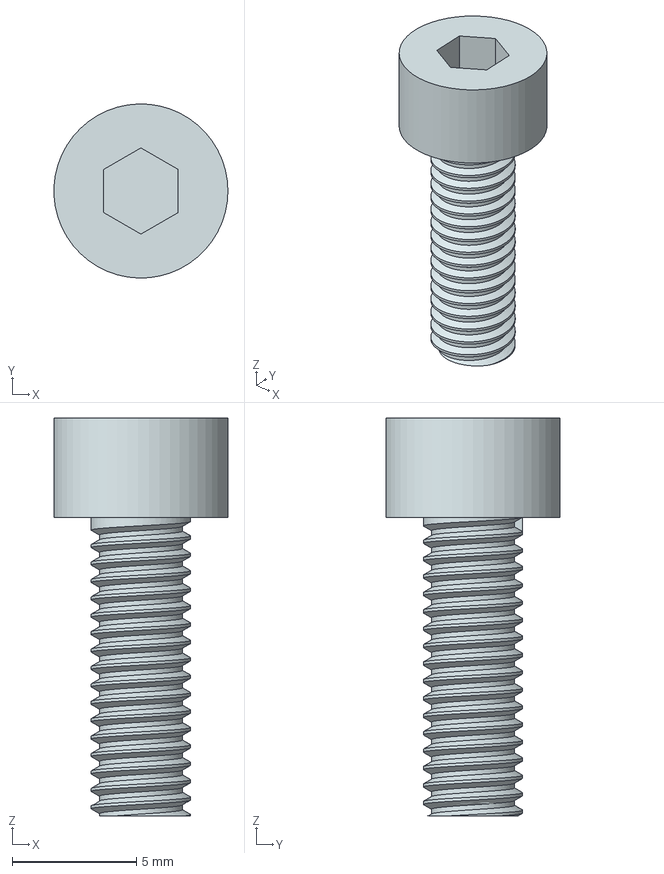
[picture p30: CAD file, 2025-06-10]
Model/M4 Allen screws/stp Files/M4x12.stp
6.99 x 7.00 x 16.0 mm

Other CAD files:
Model/M4 Allen screws/stp Files/M4x25.stp
Model/M4 Allen screws/stp Files/M4x14.stp
Model/M4 Allen screws/stp Files/M4x5.stp
Model/M4 Allen screws/stp Files/M4x30.stp
Model/0001assembly_krotki_naciag.prt
Model/0002assembly_FINAL.prt
Model/0003assembly_tylko_walek.prt
Model/000assembly_stare.prt
Model/00aranzacja.prt
Model/AM-Hex Bolt Stacks 10.prt
Model/AM-Hex Bolt Stacks 11.prt
Model/AM-Hex Bolt Stacks 12.prt
Model/AM-Hex Bolt Stacks 13.prt
Model/AM-Hex Bolt Stacks 2.prt
Model/AM-Hex Bolt Stacks 3.prt
Model/AM-Hex Bolt Stacks 4.prt
Model/AM-Hex Bolt Stacks 5.prt
Model/AM-Hex Bolt Stacks 6.prt
Model/AM-Hex Bolt Stacks 7.prt
Model/AM-Hex Bolt Stacks 8.prt
Model/AM-Hex Bolt Stacks 9.prt
Model/ASSEMBLY_BACKUP.prt
Model/Belt tensioner/2023_03_15_14_08_27_0398.prt
Model/Belt tensioner/2023_03_15_14_08_27_0414.prt
Model/Belt tensioner/2023_03_15_14_08_27_0429.prt
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

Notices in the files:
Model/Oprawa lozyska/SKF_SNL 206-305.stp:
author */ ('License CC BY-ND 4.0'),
